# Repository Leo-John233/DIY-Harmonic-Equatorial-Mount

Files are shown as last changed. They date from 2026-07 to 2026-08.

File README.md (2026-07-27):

<div align="center">
  
  
</div>

## 📄 License / 开源协议

本项目采用组合开源协议，对软件和硬件部分分别进行授权：

* **Software / 软件部分** (如固件代码): 采用 [GNU General Public License v3.0 (GPL-3.0)](LICENSE-GPL) 授权，详细信息请参阅 `LICENSE-GPL` 文件
* **Hardware / 硬件部分** (如 PCB 设计、原理图、机械 3D 模型): 采用 [CERN Open Hardware Licence Version 2 - Strongly Reciprocal (CERN-OHL-S v2)](LICENSE-CERN) 授权，详细信息请参阅 `LICENSE-CERN` 文件

若参考了该项目希望能够指明参考来源，注明原作者，保持开源精神，欢迎大家在此基础上进行改进和创新，但请勿将本项目的设计用于商业用途，除非您获得了明确许可

## 🛑致各位试图拿本开源项目“创业”的商业奇才们
本着开源精神，我非常欢迎大家复刻、交流和自己动手做着玩，但如果您是抱着“低价造个赤道仪拿去卖”的伟大商业宏图，并且打算把原作者当免费技术顾问的，请仔细阅读以下几点：

**🚫本项目不提供“保姆级开厂培训”**
开源提供的是设计本身，不是您商业化流水线上的免费技术支持，如果您连最基本的“水平轴承在哪”、“圆弧槽是干啥用的”都看不明白，连 STP 文件导入 SolidWorks 都不知道怎么处理，建议先去补习一下基础的机械常识，我不负责为您解答“怎么装”、“怎么动”、“怎么改”，更不负责给您的工厂流水线工人做技术培训，请不要把原作者当成您的“免费技术顾问”，如果您不懂机械设计，请先学会自己看图纸，学会自己分析问题，学会自己解决问题

**✂️魔改出了 Bug，请自己背锅**
把模型等比缩放、乱改减速机孔位，改完之后跑来跟我抱怨“俯仰调节机构装不上”、“没法适配”、“太难理解”？拜托，自己魔改导致的问题，请不要跑来怪原作者，我都开源了，您还指望我给您的“定制缩水版”做免费 Debug 吗？

**💰嫌贵别用，用了别嫌**
一边刷着小红书觉得这套开源设计“好高级”，一边又跑来跟我吐槽用这套方案“成本涨了200块”、“太麻烦了”，觉得贵、觉得麻烦，您可以不用，既然决定要抄这套作业去赚钱，就别在原作者面前哭穷了，毕竟我也不想看到您辛辛苦苦开了个工厂，结果因为技术问题被客户投诉了还跑来找我背锅

**⚖️友情警告**
想拿这套类似结构随便改个外观就去大规模量产售卖？自己做着玩大家其乐融融，但如果要量产商用，请自己评估好侵权风险，别怪我没提醒过您，出了事请自己承担，别拉上我，开源不等于“免费商用”，如果您想拿去商用，请自己搞定技术壁垒，做好侵权风险评估，做好售后服务准备，做好质量控制准备，做好客户投诉处理准备，做好工厂管理准备，做好资金链管理准备，做好一切商业化运营的准备，不要到时候出了问题还跑来怪原作者

大家都很忙，祝您的“平价赤道仪”大卖，Peace & Love

👉 **[奇文共赏：点击此处阅读“白嫖式创业奇才”的逆天聊天实录](https://github.com/Leo-John233/DIY-Harmonic-Equatorial-Mount/blob/main/images/Chat%20history/readme.md)**

---
## DIY谐波赤道仪（已完成实拍与导星测试）

由于我厌倦了 EQ3D 赤道仪的沉重，我计划用更轻便的谐波赤道仪来替换它。然而市面上的谐波赤道仪价格较高，尤其是与 DIY 可实现的规格相比，因此这个项目就此诞生。该谐波赤道仪旨在不牺牲性能的前提下，兼顾高精度、便携性和经济性

该项目旨在解决业余天文设备中的关键问题：
- 成品支架价格高昂
- 缺乏开放性和灵活性
- 复杂性或与个人设置的不兼容

此款DIY谐波赤道仪优势是：
- 🧰**经济实惠**——总造价低于3000元，加工零件价格低于1500元
- 🪶**相对便携**——不含底座重量7.5公斤
- 🏗️**易于搭建**——专为拥有基本工具的创客设计
- 💪**高性能**——已完成PHD2导星拍摄测试
- ⚠️**关于当前项目状态的说明**⚠️
该项目已完成通电、基础 GoTo、导星和约13kg实际成像负载下的实拍验证，稳定导星时段的 PHD2 总 RMS 通常约为 0.4″ 至 0.6″，不同装配、负载和环境下的结果可能有所差异

## ✨主要特点
| **特征** | **描述** |
| :----- | :----- |
| 安装类型 | GEM德式赤道仪 |
| 传动类型 | 谐波减速器+皮带传动+42步进电机 |
| 有效载重 | 设计最大载重 30 kg（建议配重），无配重设计载重 20-25 kg，当前已完成约 13 kg 实拍验证 |
| 减速器类型 | leaderdrive LHS-25-100-C-III |
| 控制系统 | OnStep/OnStepx |
| 连接类型 | USB-B；WIFI；蓝牙；集成DS3231SN时钟芯片 |
| 硬件功能 | RA轴制动器；RA/DEC轴光电传感器限位；DEC/RA轴光电传感器原点；<br>同时兼容step/dir，spi两种驱动模式(即兼容tmc2209，tmc5160)；12/24v输入 |
| 预计成本 | 2500-2900 RMB |
| 预计重量 | 9.5 kg（包含鸠尾槽和纬度座） |
| 已测导星表现 | 稳定时段 PHD2 总 RMS 通常约为 0.4″ 至 0.6″ |

---

## 最终成效

自制谐波赤道仪的核心部件为 Leaderdrive 拆机二手工业谐波减速器，也适用于同规格的 25-100 谐波减速器
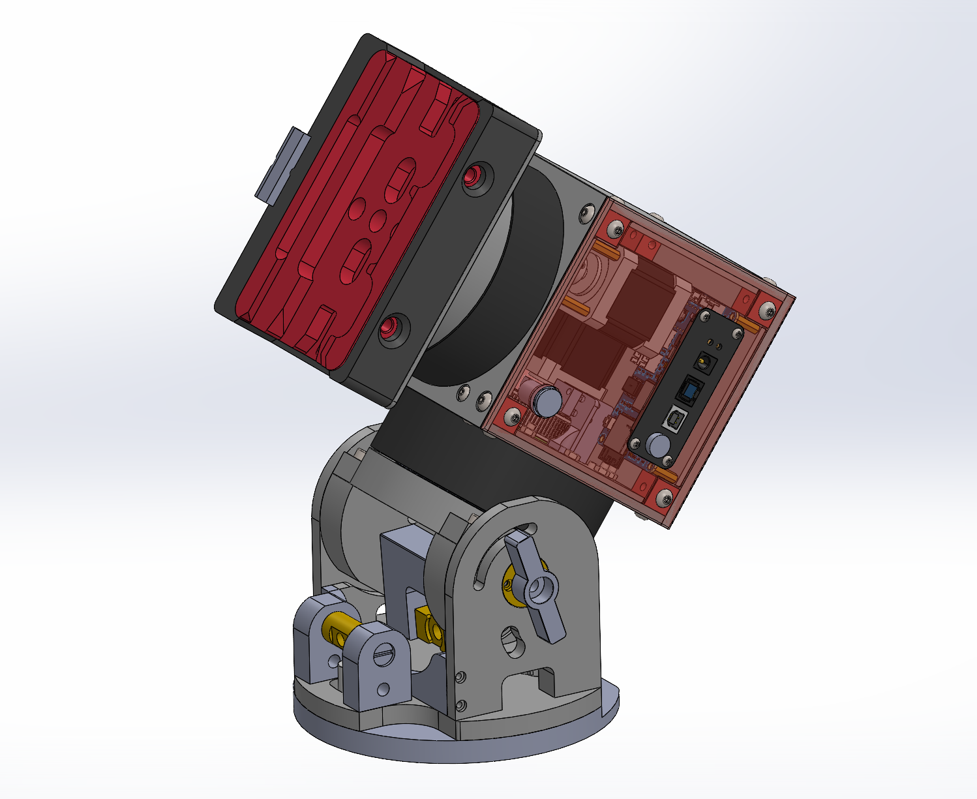
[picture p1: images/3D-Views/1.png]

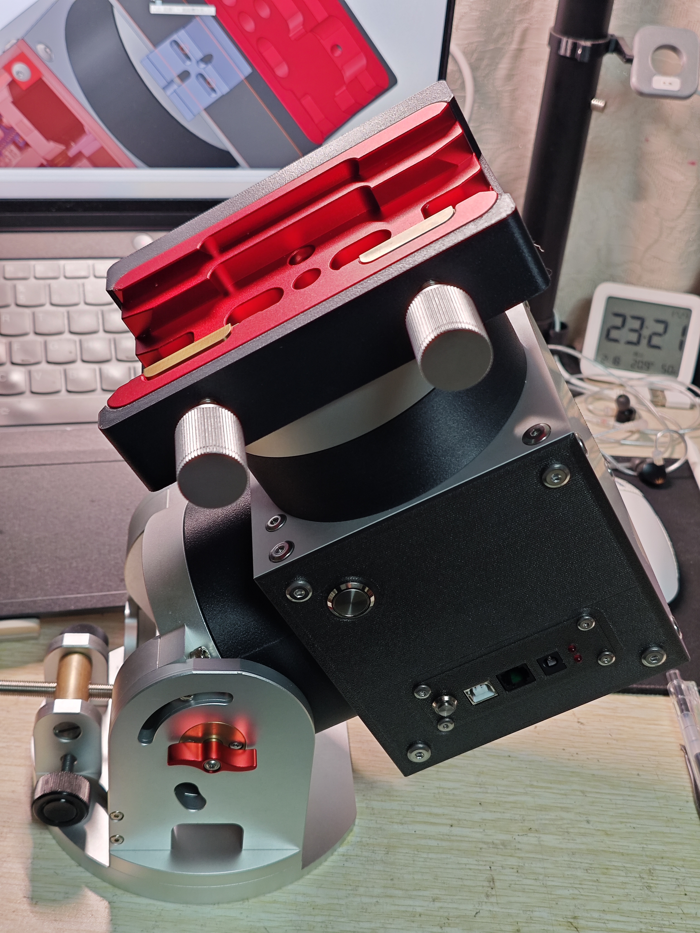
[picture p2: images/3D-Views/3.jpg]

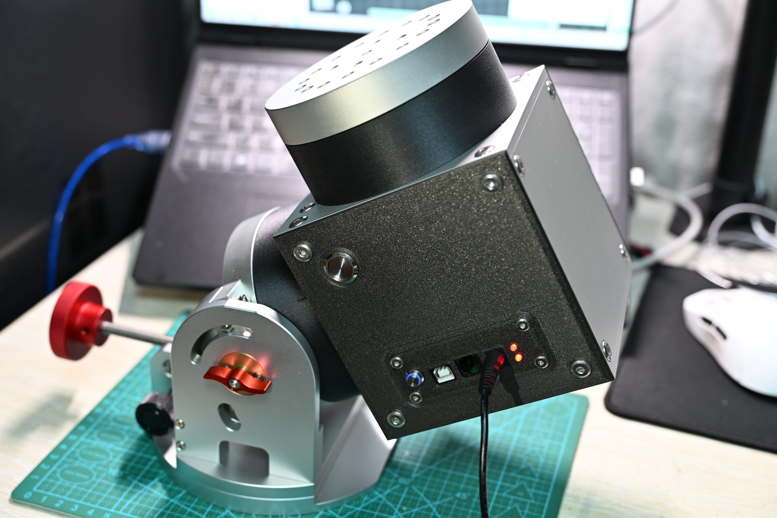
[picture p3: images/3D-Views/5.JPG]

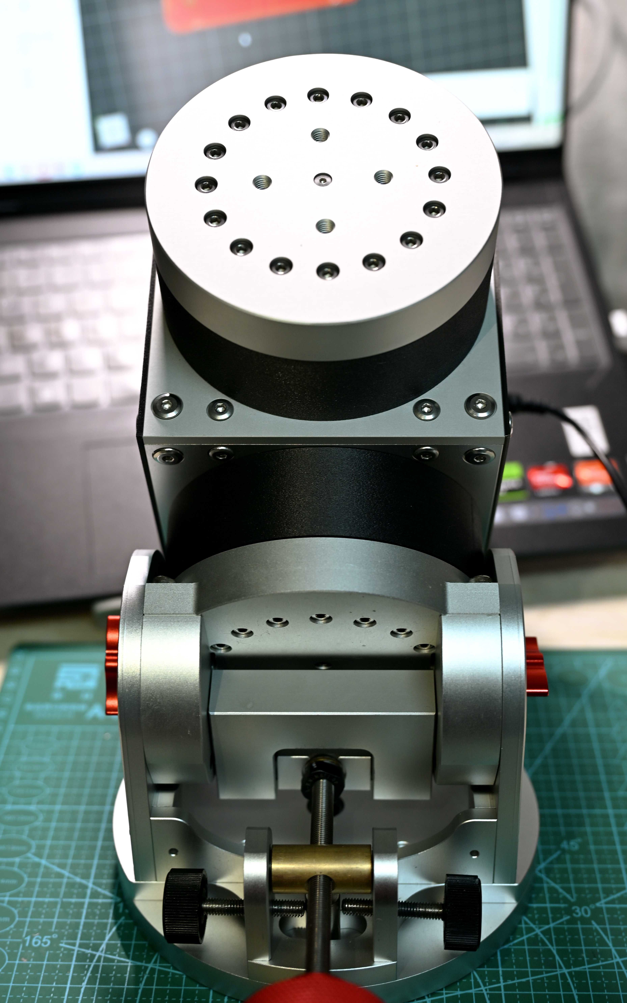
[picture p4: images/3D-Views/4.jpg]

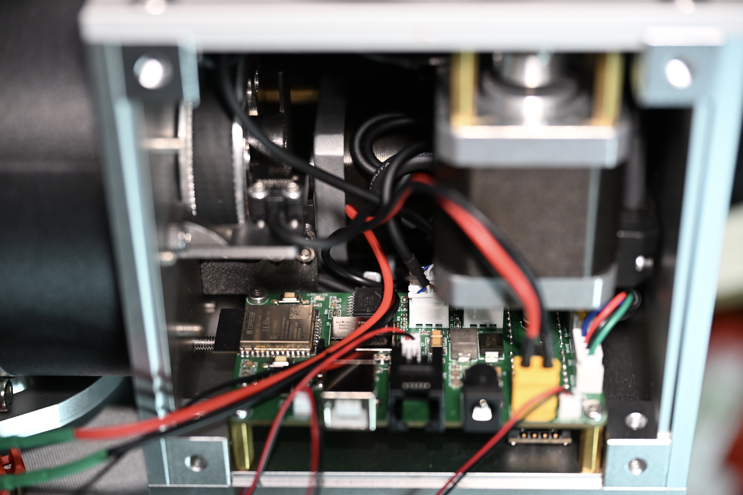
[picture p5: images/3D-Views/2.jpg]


---

## 实拍与导星测试

本次拍摄目标为 **Herschel 36**

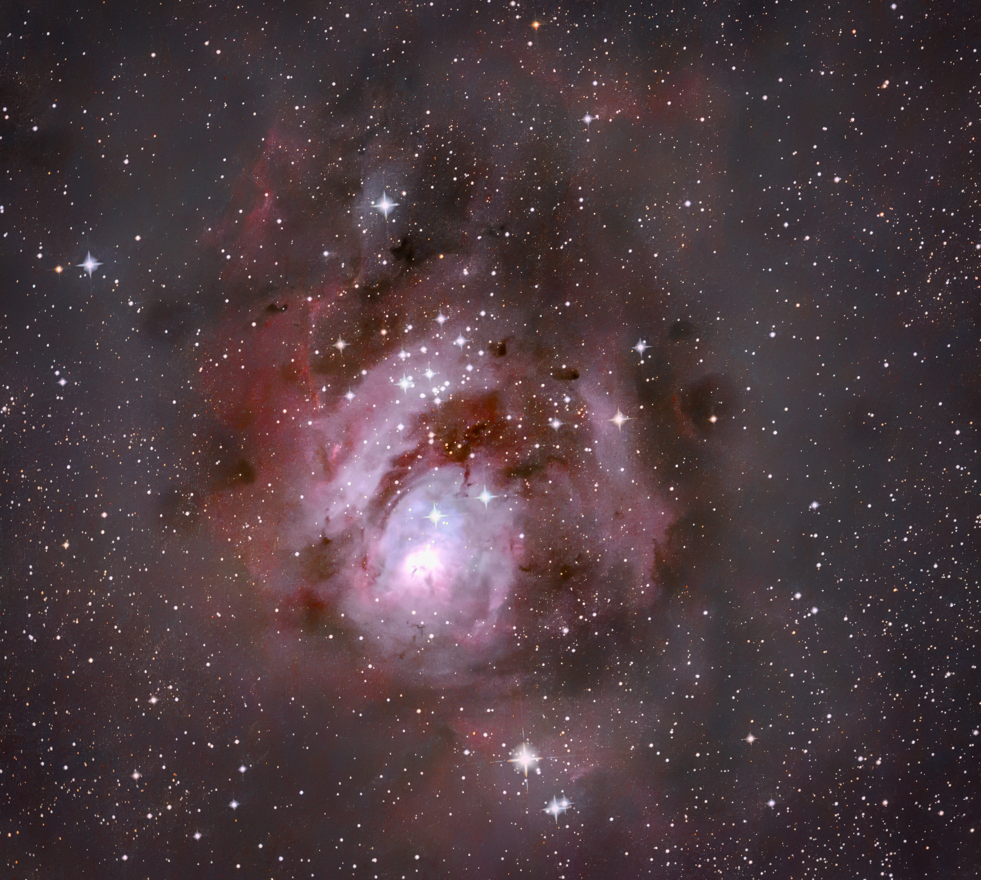
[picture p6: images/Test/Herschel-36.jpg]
Herschel 36


| **实拍项目** | **配置** |
| :----- | :----- |
| 主摄影器材 | 铁皮桶全改小黑，搭配 MPCC 彗差校正镜 |
| 主相机 | Nikon D7000 |
| 导星相机 | ZWO ASI662MC |
| 实际成像负载 | 约 13 kg |
| 测试环境 | 微风 |

## 当前验证状态

- [√] 主控板通电和基础通信
- [√] OnStep ASCOM 连接
- [√] 基础 GoTo 和恒星时跟踪
- [√] PHD2 校准和闭环导星
- [√] Dither 和 Settling
- [√] 约 52 分 45 秒连续导星记录
- [√] 约 13 kg 实际成像负载下的 Herschel 36 实拍
- [√] 不同载重和重心位置下的多夜重复测试
- [√] 无配重与带配重状态下的系统对比
- [ ] 关闭导星修正和 Dither 后的长时间本征周期误差测试
- [ ] 不同焦距、曝光时间和环境条件下的长期实拍验证

## PHD2 导星测试

### 测试配置

| 项目 | 配置 |
| :--- | :--- |
| 测试软件 | PHD2 Guiding 2.6.13 |
| 赤道仪连接 | OnStep ASCOM |
| 导星相机 | ZWO ASI662MC |
| 导星焦距 | 200 mm |
| 导星相机像元尺寸 | 2.9 μm |
| 导星图像比例 | 约 2.99″/px |
| 导星曝光 | 0.2 s |
| 实际成像负载 | 约 13 kg |
| 测试环境 | 微风 |
| 完整记录时长 | 52 分 45 秒 |

### 结果汇总

| 测试片段 | RA RMS | Dec RMS | 总 RMS | 说明 |
| :--- | ---: | ---: | ---: | :--- |
| 稳定导星片段 | 0.43″ | 0.50″ | 0.66″ | PHD2 实时统计截图 |
| 52 分 45 秒完整记录 | 0.45″ | 0.82″ | 0.94″ | 包含 Dither、Settling 和少量异常峰值 |

实际使用过程中，稳定导星阶段的总 RMS 通常约为 0.4″ 至 0.6″。稳定片段截图显示总 RMS 为 0.66″，完整记录由于包含 Dither、Settling 和少量异常峰值，总 RMS 为 0.94″

### 结果分析

- **稳定阶段两轴误差较为均衡**：RA RMS 为 0.43″，Dec RMS 为 0.50″，两轴差值较小，未表现出明显的单轴持续振荡。总 RMS 为 0.66″，按 2.99″/px 的导星图像比例换算约为 0.22 px，其中 RA 约为 0.14 px，Dec 约为 0.17 px
- **完整记录的 RMS 主要由 Dec 瞬态波动拉高**：完整记录中的 RA RMS 为 0.45″，与稳定片段接近，说明 RA 长时间表现基本保持一致。Dec RMS 上升至 0.82″，表明完整记录中的 Dither、Settling、微风或少量异常峰值主要影响了 Dec 统计结果，不代表稳定跟踪阶段持续存在 0.82″ 的 Dec 误差
- **约 13 kg 实际负载下维持稳定导星**：在铁皮桶全改小黑、Nikon D7000、MPCC 和导星系统组成的约 13 kg 成像负载下，稳定阶段未观察到明显发散或持续性机械振荡，说明当前结构刚性、传动控制和导星响应能够满足实际成像需求
- **0.2 s 导星曝光体现了较快的修正响应**：较短曝光有助于快速修正误差，但也更容易受到视宁度和瞬时扰动影响。因此，0.4″ 至 0.6″ 应视为本次设备、参数和环境组合下的实测表现，不应直接作为所有场景下的固定性能指标
- **频域结果不能直接作为本征周期误差**：频域分析中选中的低频分量周期约为 2206.6 s，显示振幅约为 0.1″。由于数据来自导星记录，并包含低频漂移、Dither 和 Settling，该结果只能用于观察频率成分，不能直接认定为谐波减速器的本征周期误差

<details>
<summary>展开查看 PHD2 测试截图与频域分析</summary>

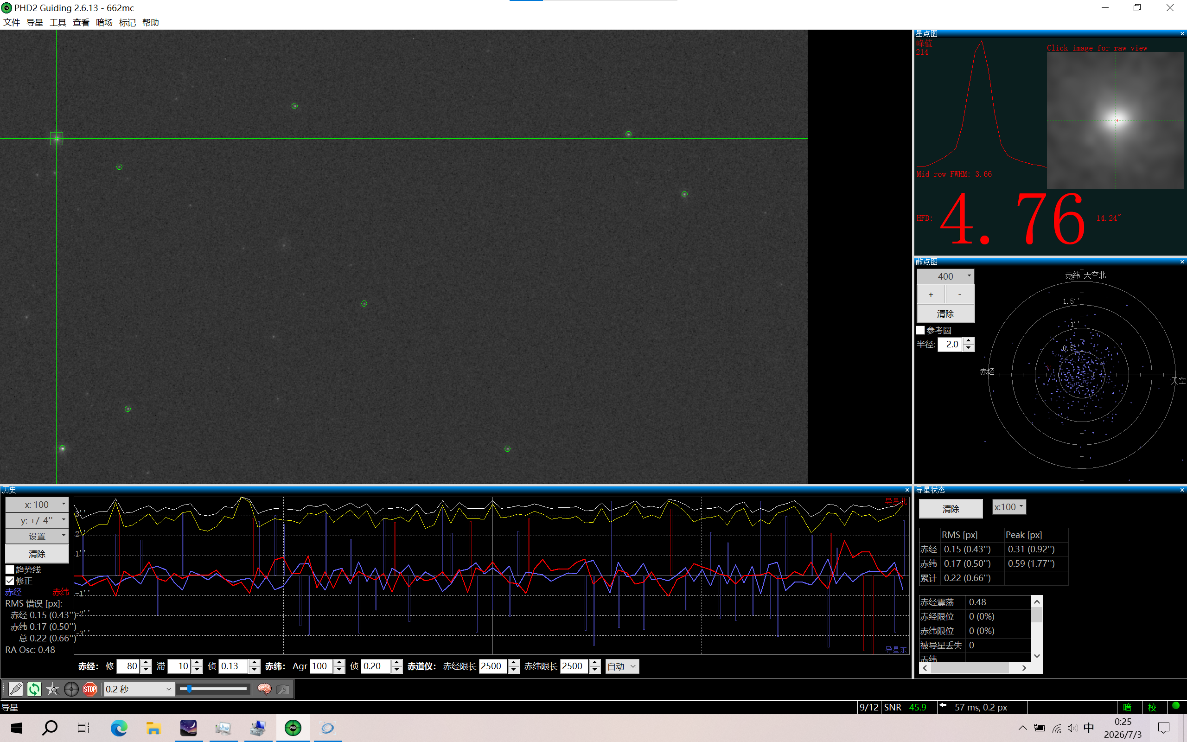
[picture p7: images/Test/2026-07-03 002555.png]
PHD2 stable guiding


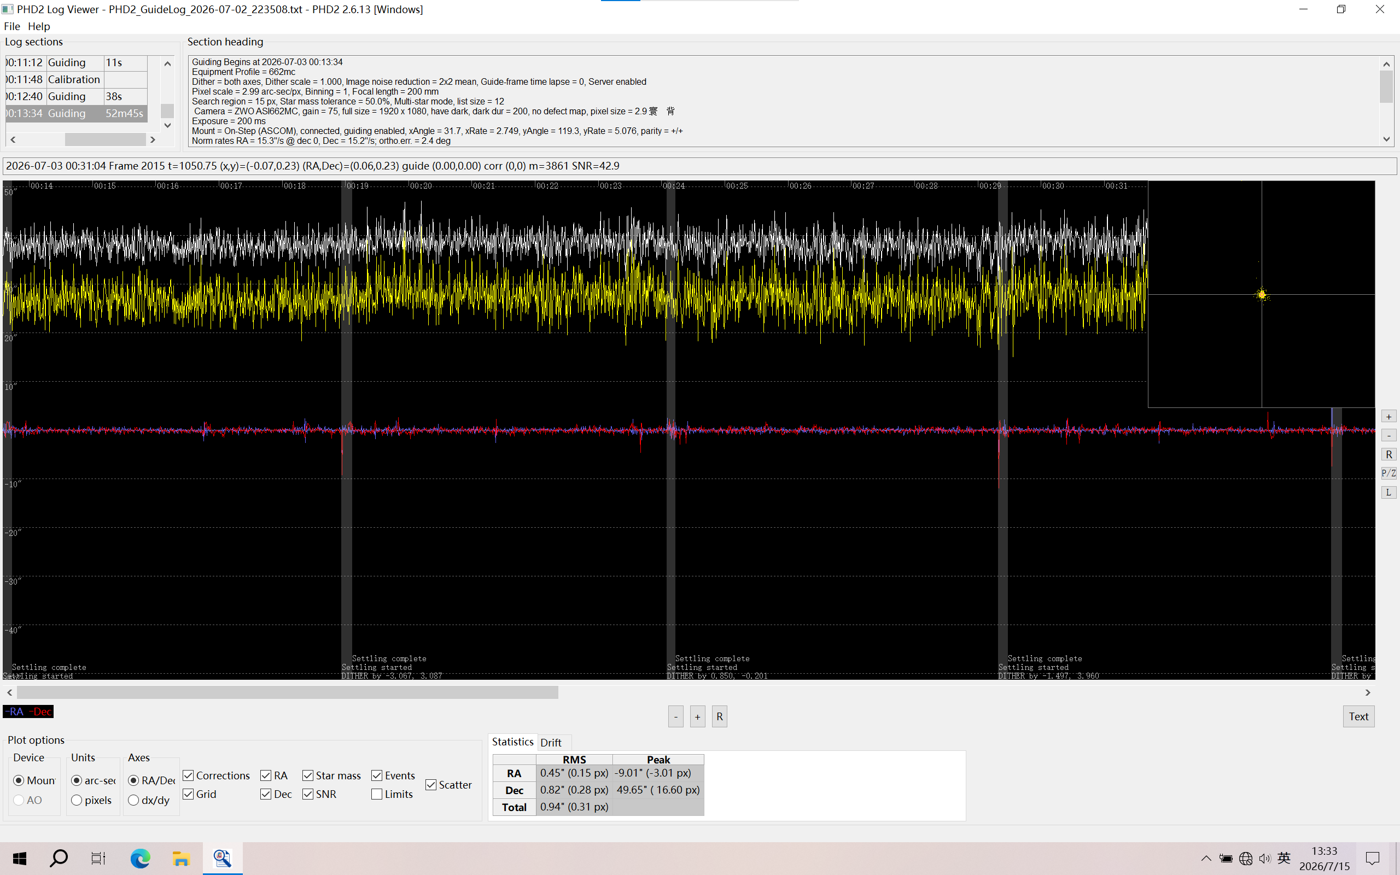
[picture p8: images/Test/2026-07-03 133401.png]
PHD2 complete log


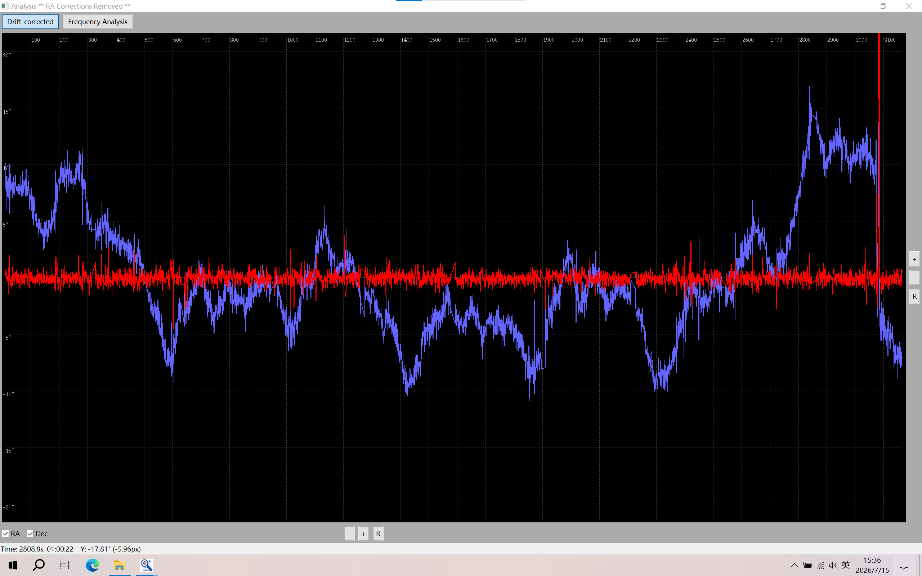
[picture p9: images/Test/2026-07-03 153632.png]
PHD2 drift-corrected analysis


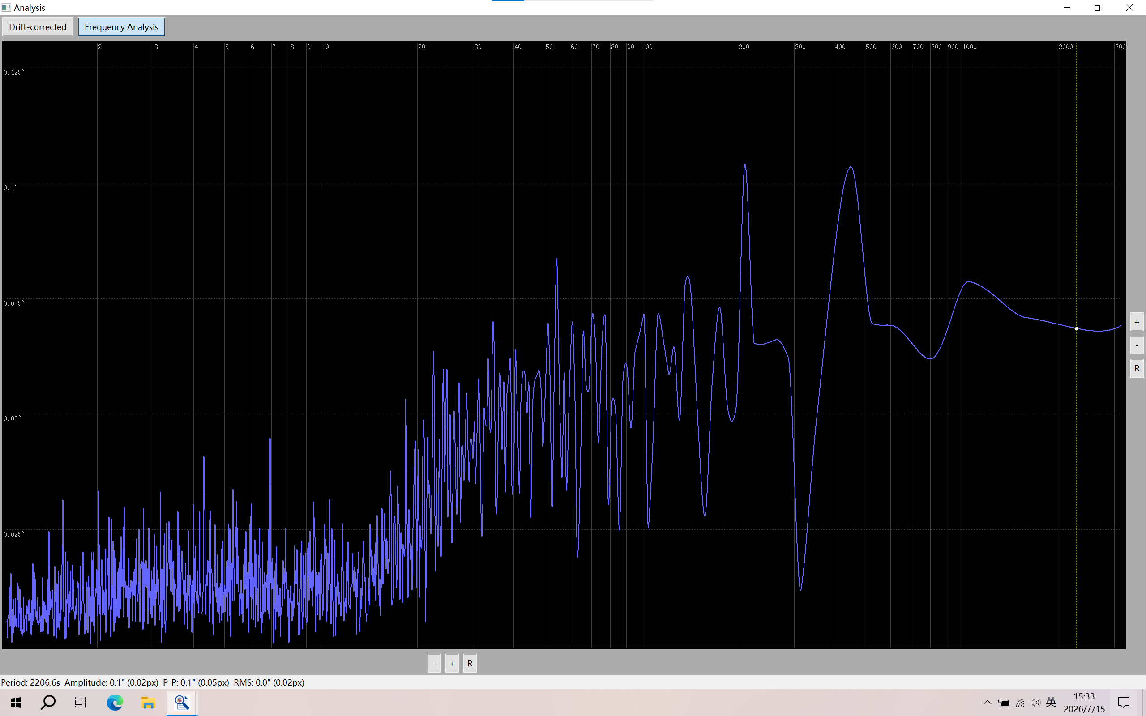
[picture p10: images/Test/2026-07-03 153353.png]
PHD2 frequency analysis


移除 RA 导星修正后的曲线仍包含低频漂移、Dither 和 Settling 的影响，不能直接将整段曲线的峰峰值视为谐波减速器的本征周期误差

频域分析中选中的低频分量周期约为 2206.6 s，软件显示振幅约为 0.1″。该结果仅用于观察频率成分，不能替代关闭导星修正和 Dither 后进行的长时间无导星周期误差测试

</details>

---

## 🔗 物料清单 (BOM)

请参阅 [BOM.md](https://github.com/Leo-John233/DIY-Harmonic-Equatorial-Mount/tree/main/BOM)

**预计总成本：约2500RMB（含纬度座）**

本项目的主体结构高度依赖定制，主要部件包含两台 25-100 规格的谐波减速器，提供了极高的传动比与扭矩，底座接口可根据个人习惯适配主流的三脚架

*注：价格为近似值，可能因电机供应商、CNC 加工批次和地点而异*

---

## 🔌电子部分概览

控制系统完全采用定制设计，并围绕紧凑结构构建，它包括：

* **基于 ESP32-WROOM-32E16N 的主控核心**，运行强大的 [OnStep/OnStepX](https://onstep.groups.io/g/main/wiki) 系统
* **搭配 ESP07S 无线连接**，提供高效的无线/有线通讯
* **TMC系列步进电机驱动器**，实现赤经与赤纬轴精确、静音的微步进控制与指向
* **高效电源管理方案**，板载 TPS5450 降压模块和 AMS1117 LDO 稳压芯片，确保高负载下系统电压的纯净与稳定
* 集成 **零位传感器和限位开关** 接口，在运行中保障设备的安全
* 支持通过 Wi-Fi、蓝牙或 USB 路由进行远程控制，无缝对接主流天文摄影软件生态 (N.I.N.A., INDI, ASCOM 等)
* 控制板在 PCB 走线设计上充分考虑了扩展性需求，通过主板驱动器插槽旁的排针跳线 (Jumpers)，您可以轻松地在先进的 **SPI 智能控制模式**和传统的 **STEP/DIR 独立模式**之间进行物理切换(切换后需刷写固件)

* **TMC5160 SPI 模式 (推荐配置) 🚀**
    * **硬件设置**：使用跳线帽闭合 SPI 专用的针脚组，将 ESP32 的 SPI 总线直接连接至 TMC5160 驱动器
    * **系统优势**：彻底告别手动调节电位器，允许 OnStep 固件直接读取和写入寄存器，您可以在 Web 界面或 `Config.h` 中实时配置运行/保持电流、精确设置细分数（Microstepping），并在 StealthChop（极致静音）和 SpreadCycle（高动态扭矩）模式之间智能切换，最大化释放谐波减速器的性能
    * **固件配合**：在 `Config.h` 中将赤经/赤纬驱动模型定义为 `TMC5160_SPI`

* **传统 STEP/DIR 模式 (向下兼容) 🔌**
    * **硬件设置**：断开 SPI 通讯跳线
    * **适用场景**：作为一种可靠的底层回退方案。如果您需要临时替换为普通的 A4988、DRV8825，或者仅使用 TMC 驱动器的 Standalone (独立运行) 模式，此设计提供了极大的硬件容错率和维修便利性
    * **固件配合**：需要在 `Config.h` 中精确填写您通过跳线帽设定的细分值，并**必须手动使用万用表和陶瓷螺丝刀**调节驱动器上的 VREF 电位器来设定电机电流

所有电路板原理图及 PCB Layout（严格把控了安全间距、过孔尺寸和大电流线宽）均使用开源工具设计，您可以在 [JLC PCB](https://member.jlc.com/?spm=PCB.Homepage) 订购 PCB或对其进行重新组合以满足您的需求

### PCB 制作与装配说明

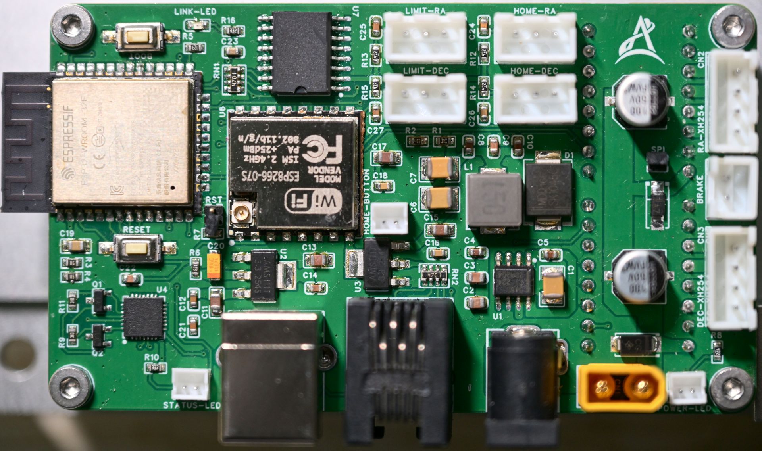
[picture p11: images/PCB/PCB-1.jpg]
PCB front


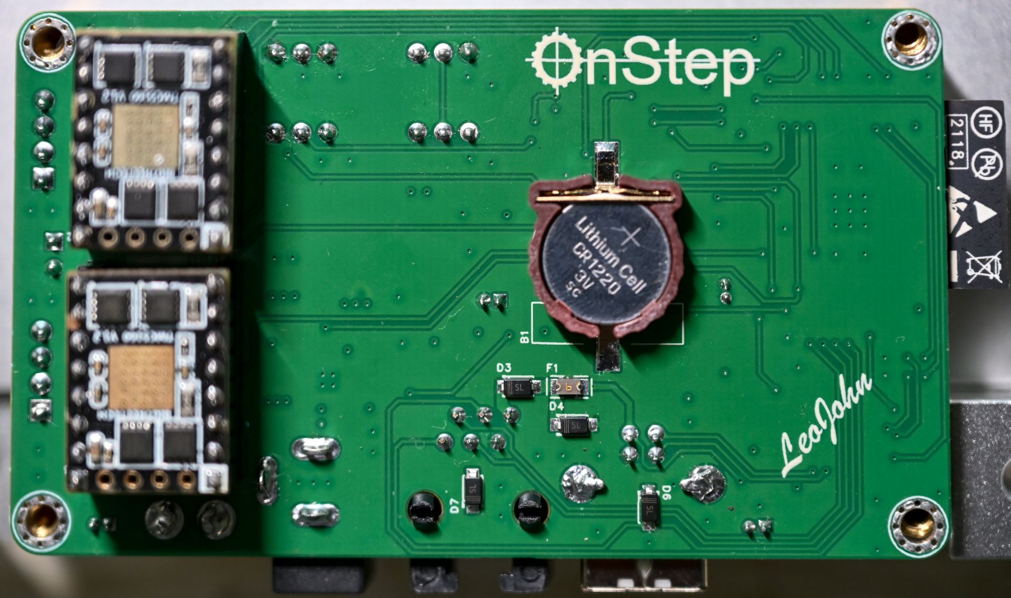
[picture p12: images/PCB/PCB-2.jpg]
PCB reverse-side TMC5160 installation


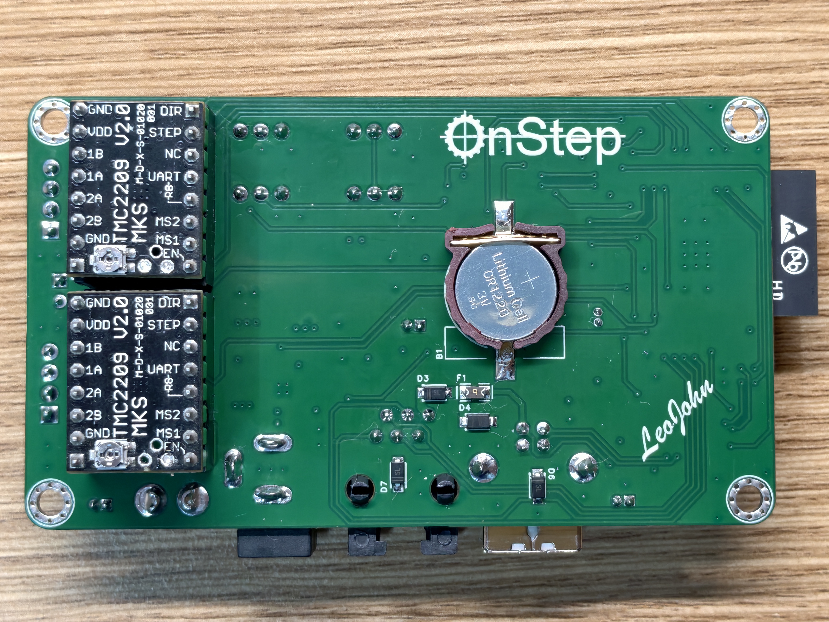
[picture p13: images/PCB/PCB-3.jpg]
PCB reverse-side TMC2209 installation


PCB 制作和装配建议按以下顺序进行：

1. **提交 PCB 文件**
   * 将仓库中对应版本的 Gerber 压缩包直接上传至 PCB 厂商
   * 下单前检查板框尺寸、安装孔、槽位和连接器开口，避免生产平台自动缩放或修改外形
   * 如果自行修改板厚、铜厚、表面处理或元件封装，需要重新确认外壳间隙、连接器高度和大电流走线能力

2. **核对元件和方向**
   * 焊接前根据原理图、BOM、PCB 丝印和封装方向逐项核对元件
   * 重点检查二极管、LED、电解电容、稳压芯片、ESP32、ESP-07S 和其他有方向要求的器件
   * CR1220 电池按 PCB 丝印方向安装，照片所示安装方式为正极朝外
   * ESP32 天线区域附近不要布置金属挡板、屏蔽片或紧贴外壳，以免影响无线连接

3. **建议焊接顺序**
   * 先焊接电阻、电容、二极管和小型 IC 等低矮贴片器件
   * 再焊接电源模块、排针、驱动器插座、按键和 LED 接口
   * 最后安装 XH2.54 插座、USB、网络接口、DC 插座、XT60 和其他较高连接器
   * TMC 驱动器、ESP 模块和纽扣电池应在完成短路检查和基础供电测试后再安装

4. **驱动器安装**
   * 驱动器安装在 PCB 背面，插入前必须核对 PCB 丝印与驱动器上的 `GND`、`VM`、`EN`、`STEP` 和 `DIR` 引脚
   * 不同厂商的 TMC2209 或 TMC5160 模块可能存在引脚、焊盘或散热结构差异，不能只根据模块外观判断方向
   * 使用 TMC5160 SPI 模式时闭合对应 SPI 跳线，并在固件中选择 `TMC5160_SPI`
   * 使用 TMC2209 或其他 STEP/DIR 驱动器时断开 SPI 跳线，并按照实际硬件设置填写细分参数和驱动电流
   * 驱动器插反或带电插拔可能立即损坏驱动器和主控板

5. **首次通电检查**
   * 通电前使用万用表检查主电源正负极之间是否存在明显短路
   * 首次测试建议使用带限流功能的实验电源，并从较低限流值开始
   * 首次通电时不要连接电机、传感器和驱动器，先确认电源部分没有异常发热，并检查主要电压轨是否正常
   * 确认主控、USB 通信和无线连接正常后，再逐个安装驱动器并连接 RA、Dec 电机
   * 初次电机测试应使用较低电流和较低速度，确认转向、原点和限位逻辑正确后再提高参数

6. **接口连接**
   * `LIMIT-RA`、`LIMIT-DEC`、`HOME-RA` 和 `HOME-DEC` 分别连接对应轴的限位和原点传感器
   * `RA-XH2.54`、`DEC-XH2.54` 和 `BRAKE` 接口应根据原理图确认引脚顺序后连接
   * 状态灯、连接灯和电源灯接口需要注意 LED 极性
   * 不建议同时连接多个主电源入口，除非已根据原理图确认其连接关系和使用方式

> 💡**警告：任何焊接、驱动器插拔、跳线调整、传感器接线或电机接线操作都必须在主电源和 USB 供电完全断开后进行，首次上电前应再次检查电源极性、焊锡短路、驱动器方向和连接器引脚顺序**

## 💻固件配置与刷写

谐波赤道仪的主控搭载了 **ESP32-WROOM-32E (16MB)**，这款大容量核心不仅能轻松运行复杂的 [OnStep / OnStepX](https://onstep.groups.io/g/main/wiki) 固件，还为内置星表、高精度对位模型 (Pointing Model) 以及功能丰富的 Smart Web UI 留出了充足的存储空间

请参阅 [Firmware_Setup.md](https://github.com/Leo-John233/DIY-Harmonic-Equatorial-Mount/blob/main/software/Firmware_Setup.md) 获取完整的 `Config.h` 参数表及详细引脚映射

---

## 🛠️机械部分组装指南

请参阅 [Assembly.md](https://github.com/Leo-John233/DIY-Harmonic-Equatorial-Mount/blob/main/hardware/Assembly.md)

每个组件都经过精心挑选或设计，以确保高机械精度和易于组装，从 CNC 加工的坚固铝制主体、25-100 谐波减速器，到步进电机和控制器的 3D 打印防护外壳，每一步都经过了严格的测试与指向模型校准，以实现亚角秒级的跟踪精度

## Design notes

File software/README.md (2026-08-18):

---

## 📝 摘要 (Summary)

本项目以 [原始 OnStep 4.24](https://github.com/hjd1964/OnStep/tree/release-4.24) 为对照基准，说明本地固件针对 MaxESP3 谐波赤道仪做出的实际修改

修改围绕三条主线展开，开机后先建立保持力矩并确认位置，运动中保留安全中断与反向脱困能力，驱动细分切换时保持双轴同步

具体改进包括开机电机保持、位置可信状态、GOTO 与 Tracking 安全锁、物理限位反向脱困、三阶段自动回零、GOTO 中断分类、客户端状态修复以及 MaxESP3 TMC2209 共享细分切换

本文只展示本地代码相对原始 OnStep 4.24 新增或改进的实现，不重复粘贴未修改的上游代码

---

## 📌 背景与痛点 (Pain Points)

原始 OnStep 4.24 是面向多种赤道仪和经纬仪的通用固件。将它用于当前 MaxESP3 谐波赤道仪时，还需要处理下面这些实际问题

1. **开机可能溜车**

   谐波赤道仪通常没有传统离合结构。镜筒失衡时，如果驱动器在上电初期没有保持力矩，机械结构可能在重力作用下滑落

2. **上电位置不能直接信任**

   开环步进系统断电后无法证明机械位置没有变化。Home 传感器启用时，开机后的坐标只能在真实回零完成后重新建立

3. **未回零时自动动作风险较高**

   N.I.N.A、ASCOM 或其他 LX200 客户端可能在连接后发送 GOTO、Sync、Park 或 Tracking 指令。如果当前位置不可信，自动动作可能造成错误指向、绕线或机械碰撞

4. **安全中断后不能恢复成正常到达**

   GOTO 因限位、驱动故障或回零失败而停止时，不能继续走正常完成流程，更不能在错误坐标上自动开始 Tracking

5. **触发物理限位后仍需要反向脱困**

   如果限位触发后锁死所有手动方向，设备会停在开关上无法退出。如果完全不限制方向，又可能继续向危险侧运动

6. **Home 开关位置不一定是真实机械零位**

   传感器安装位置与目标零位可能存在角度偏差，需要在快速搜索和慢速精找后继续执行可配置的双轴偏置

7. **回零失败不能伪装成成功**

   传感器未触发、阶段超时或电机启动失败时，系统必须保留位置恢复要求，不能只因为回零状态机结束就开放 GOTO

8. **MaxESP3 的共享模式引脚需要双轴同步处理**

   MaxESP3 的 Axis1 与 Axis2 共用 M0 和 M1。独立模式 TMC2209 如果按原始双轴独立逻辑切换细分，可能出现硬件细分已经改变而软件步距没有同步的问题

9. **首次连接可能误报 Home**

   `atHome` 只能说明内部状态位于 Home，不能单独证明当前机械位置可信。客户端状态必须同时检查位置恢复状态

10. **有无 Home 传感器都需要可恢复路径**

    有传感器时可以自动 Find Home，没有传感器时则需要保留坐标 Home 和人工 Set Home 的恢复方式，不能被新增安全锁永久限制

---

## ✨ 核心功能特性 (Key Features)

1. **开机电机保持**

   上电后使能双轴驱动器，使用跟踪细分和跟踪电流保持当前位置，但不启动 Tracking，也不声明已经完成 Home

2. **独立的位置可信状态**

   使用 `mountPositionTrusted` 与 `positionRecoveryRequired` 区分正常使用、仅允许坐标回零和位置完全不可信三种状态

3. **自动命令统一进入安全检查**

   GOTO、Sync、Park 和开启 Tracking 都依赖 `positionReady()`，不会因为命令入口不同而绕过回零要求

4. **未回零仍允许手动移动**

   手动 East、West、North、South 不依赖位置可信状态，方便用户找零、调整姿态和处理机械风险

5. **物理限位反向脱困**

   限位触发后记录危险方向，只拒绝继续撞击的一侧，允许相反方向手动退出

6. **三阶段自动回零**

   自动 Home 依次执行快速搜索、慢速精找和零位偏置，双轴全部停稳后才重建坐标

7. **ST4 长按一键回零**

   同时长按 East 和 West 超过 3 秒可启动快速回零，并通过按键锁避免残留输入干扰状态机

8. **GOTO 中断分类**

   区分普通停止、物理硬停止和位置丢失，按风险等级决定是否停止 Tracking 和要求重新 Home

9. **客户端状态修复**

   `:GU#` 只有在 `atHome` 与 `positionReady()` 同时成立时才返回 `H`。被拒绝的 `:Te#` 会立即回复失败，不再让客户端等待通信超时

10. **MaxESP3 TMC2209 共享细分支持**

    双轴共享 M0 和 M1 时统一判断 GOTO 模式，在可安全切换的位置同步更新硬件模式与软件步距

11. **配置校验与中文说明**

    新增开机策略、回零速度、偏置角度和共享细分规则校验，并在 `Config.h` 与 MaxESP3 引脚文件中补充中文说明

---

## 🛠️ 代码修改与源码对照 (Code Modification Guide)

下表汇总本地代码相对原始 OnStep 4.24 的 20 项修改。后文按相同编号给出修改代码和功能说明

| 编号 | 修改主题 | 主要文件 | 相对原始 OnStep 4.24 的变化 | 修改带来的功能 |
| --- | --- | --- | --- | --- |
| 1 | 开机保持与位置确认 | `Config.h` `OnStep.ino` | 新增开机回零要求和电机保持策略 | 上电后保持双轴但不启动 Tracking |
| 2 | 位置可信模型 | `OnStep.ino` | 新增位置可信状态 恢复状态和 GOTO 中断类型 | 区分正常使用 坐标回零恢复和位置丢失 |
| 3 | ST4 一键回零 | `Guide.ino` | 新增长按 East 与 West 启动回零的按键逻辑 | 无需上位机即可触发自动回零 |
| 4 | GOTO 与 Sync 安全锁 | `Goto.ino` | 将 `positionReady()` 纳入 GOTO 和 Sync 校验 | 位置恢复前禁止自动指向和同步 |
| 5 | Tracking 失败反馈 | `Command.ino` | 开启 Tracking 前检查位置并立即返回结果 | 避免错误启动和客户端通信超时 |
| 6 | Park 安全锁 | `Park.ino` | Park 前增加位置可信检查 | 防止使用错误坐标执行驻留 |
| 7 | Guide 反向脱困 | `Guide.ino` | 按限位方向拦截 Guide 并保留反向移动 | 阻止继续撞限位同时允许退出危险位置 |
| 8 | 物理限位方向记录 | `OnStep.ino` | 记录双轴危险方向并判断是否已经逃离限位 | 实现硬停止和反向移动后的自动解锁 |
| 9 | Home 状态修复 | `Command.ino` | `:GU#` 同时检查 `atHome` 和 `positionReady()` | 避免客户端首次连接误报已经回零 |
| 10 | 三阶段自动回零 | `Home.ino` | 新增慢速精找和零位偏置阶段 | 从找到传感器提升为恢复真实机械零位 |
| 11 | Home 参数配置 | `Config.h` `Home.ino` | 回零速度 超时和双轴偏置改为可配置 | 便于适配不同传动比和传感器位置 |
| 12 | 回零失败保护 | `Home.ino` | 阶段超时或电机启动失败时保留位置锁 | 防止失败流程被当作回零成功 |
| 13 | 回零成功判定 | `Home.ino` | 只在 `FH_DONE` 中重新建立可信位置 | 确保全部阶段完成后才开放自动动作 |
| 14 | 无传感器恢复路径 | `Home.ino` | `HOME_SENSE` 关闭时保留坐标 Home | 无传感器配置仍可完成位置恢复 |
| 15 | 人工 Set Home 恢复 | `Home.ino` | Set Home 后统一清除中断并恢复可信位置 | 提供明确的人工位置恢复入口 |
| 16 | 坐标 Home 中断保护 | `MoveTo.ino` | 检查坐标 Home 是否完整结束 | 中断的回零不会错误解除位置锁 |
| 17 | GOTO 分类收尾 | `Goto.ino` `MoveTo.ino` | 按正常到达 普通停止 硬停止和位置丢失分别处理 | 防止安全中断后自动进入 Tracking |
| 18 | 停止等级标记 | `OnStep.ino` | `stopSlewingAndTracking()` 按停止来源写入中断等级 | 按风险决定是否要求重新回零 |
| 19 | MaxESP3 引脚与校验 | `Pins.MaxESP3.h` `Validate.MaxESP3.h` `Validate.h` `Validate.TMC2209.h` | 重整引脚定义并增加共享模式配置校验 | 让固件配置匹配本地 MaxESP3 硬件 |
| 20 | TMC2209 双轴细分切换 | `Timer.ino` `StepMode.ino` | 共享 M0 和 M1 时同步切换双轴硬件模式与软件步距 | 在 Tracking 与 GOTO 间切换时保持双轴坐标一致 |

### 1. 开机自动使能电机并要求位置确认

- **对照基准**：原始 OnStep 4.24 没有独立的开机回零要求和电机保持选项
- **修改文件**：`Config.h`、`OnStep.ino`
- **修改逻辑**：新增三个彼此独立的策略开关，并在启动流程中分别处理位置状态和驱动器保持

```cpp
// Config.h
#define HOME_REQUIRED_ON_BOOT          ON
#define HOME_REQUIRED_AFTER_LIMIT      ON
#define MOTOR_HOLD_ON_BOOT             ON
```

```cpp
// OnStep.ino
#if HOME_REQUIRED_ON_BOOT == ON
  #if MOUNT_TYPE != ALTAZM
    #if HOME_SENSE == OFF
      requireCoordinateHomeRecovery();
    #else
      invalidatePositionReference();
    #endif

    gotoAbortState = GOTO_ABORT_NONE;
    trackingState = TrackingNone;
    lastTrackingState = TrackingNone;
    abortTrackingState = TrackingNone;
    safetyLimitsOn = false;
  #endif
#endif

#if MOTOR_HOLD_ON_BOOT == ON
  #if MOUNT_TYPE != ALTAZM
    enableStepperDrivers();
    axis1DriverTrackingMode(false);
    axis2DriverTrackingMode(false);
  #endif
#endif
```

**修改带来的功能**

开机后电机立即获得保持力矩。Tracking 保持关闭，有 Home 传感器时位置被标记为不可信，没有 Home 传感器时只保留返回坐标 Home 的能力

---

### 2. 新增位置可信状态与 GOTO 中断分类

- **对照基准**：原始 OnStep 4.24 主要依赖 `atHome`、`trackingState` 和 `generalError`，没有独立的位置可信模型
- **修改文件**：`OnStep.ino`
- **修改逻辑**：新增位置状态、恢复状态和 GOTO 中断类型

```cpp
enum GotoAbortState {
  GOTO_ABORT_NONE,
  GOTO_ABORT_STOPPED,
  GOTO_ABORT_HARD_STOP,
  GOTO_ABORT_POSITION_LOST
};

GotoAbortState gotoAbortState = GOTO_ABORT_NONE;
bool gotoStartTrackingOnSuccess = false;
bool mountPositionTrusted = true;
bool positionRecoveryRequired = false;
```

```cpp
bool positionReady() {
  return mountPositionTrusted && !positionRecoveryRequired;
}

bool positionHomeReturnOnly() {
  return mountPositionTrusted && positionRecoveryRequired;
}

void requireCoordinateHomeRecovery() {
  mountPositionTrusted = true;
  positionRecoveryRequired = true;
  gotoStartTrackingOnSuccess = false;
}

void invalidatePositionReference() {
  mountPositionTrusted = false;
  positionRecoveryRequired = true;
  gotoStartTrackingOnSuccess = false;
}

void completePositionRecovery() {
  mountPositionTrusted = true;
  positionRecoveryRequired = false;
  gotoAbortState = GOTO_ABORT_NONE;
  gotoStartTrackingOnSuccess = false;
  clearPhysicalLimitState();
}
```

**修改带来的功能**

停止运动不再等于位置可信。限位、故障、回零失败和正常停止可以进入不同的恢复路径，所有自动动作共用同一套位置判断

---

### 3. 复用 ST4 接口实现实体按键一键回零

- **对照基准**：原始 OnStep 4.24 的 East 与 West 长按用于 Alt Mode，没有 3 秒 Find Home 入口
- **修改文件**：`Guide.ino`
- **修改逻辑**：增加 3 秒组合键和释放锁，保留原有 2 秒 Alt Mode

```cpp
static bool homingLockout = false;

if (homingLockout) {
  if (!st4e.isDown() && !st4w.isDown() &&
      !st4n.isDown() && !st4s.isDown()) {
    homingLockout = false;
  }
  return;
}

if (trackingState != TrackingMoveTo && !waitingHome) {
  if (st4e.isDown() && st4w.isDown()) {
    if (st4e.timeDown() > 3000 && st4w.timeDown() > 3000) {
      homingLockout = true;
      soundBeep();
      altModeA = false;
      stopGuideAxis1();
      stopGuideAxis2();
      stopSlewingAndTracking(SS_ALL_FAST);
      goHome(true);
      return;
    }
  }
}
```

**修改带来的功能**

不连接电脑也能启动自动回零。触发后会清理 Alt Mode 和当前运动，全部按键松开后才恢复 ST4 输入，避免残留按压干扰回零

---

### 4. 统一拦截未恢复状态下的 GOTO 与 Sync

- **对照基准**：原始 `validateGoto()` 只检查 Park、电机使能、运动状态和驱动故障
- **修改文件**：`Goto.ino`
- **修改逻辑**：在所有 GOTO 与 Sync 共用的校验函数中加入 `positionReady()`

```cpp
CommandErrors validateGoto() {
  if (parkStatus != NotParked)                 return CE_SLEW_ERR_IN_PARK;
  if (!axis1Enabled)                           return CE_SLEW_ERR_IN_STANDBY;
  if (trackingSyncInProgress())                return CE_MOUNT_IN_MOTION;
  if (trackingState == TrackingMoveTo)         return CE_GOTO_ERR_GOTO;
  if (guideDirAxis1 || guideDirAxis2)          return CE_MOUNT_IN_MOTION;
  if (faultAxis1 || faultAxis2)                return CE_SLEW_ERR_HARDWARE_FAULT;
  if (!positionReady())                        return CE_SLEW_ERR_IN_STANDBY;
  return CE_NONE;
}
```

**修改带来的功能**

`:MS#`、Sync 和其他自动指向入口都无法绕过位置检查。位置未恢复时返回 standby，上游原有的地平线、双轴范围、中天和墩侧校验继续保留

---

### 5. Tracking 指令被拦截时立即回复失败

- **对照基准**：原始 `:Te#` 没有位置可信检查
- **修改文件**：`Command.ino`
- **修改逻辑**：只拦截开启 Tracking，不影响停止 Tracking，并保留布尔回复

```cpp
if (command[0] == 'T' && parameter[0] == 0) {
  const bool trackingBlockedUntilRecovery =
    command[1] == 'e' && !positionReady();

  if (trackingBlockedUntilRecovery) {
    commandError = CE_SLEW_ERR_IN_STANDBY;
  } else {
    // 原始 Tracking 命令继续处理
  }
}
```

**修改带来的功能**

位置不可信时 `:Te#` 不会启动恒星跟踪。命令处理器会立即返回 `0`，避免 N.I.N.A 或 ASCOM 一直等待到通信超时

---

### 6. Park 位置增加可信状态检查

- **对照基准**：原始 OnStep 4.24 在设备停止且驱动无故障时即可保存 Park 位置
- **修改文件**：`Park.ino`
- **修改逻辑**：保存 Park 前增加位置可信检查

```cpp
CommandErrors setPark() {
  if (parkStatus == ParkFailed)         return CE_PARK_FAILED;
  if (parkStatus == Parked)             return CE_PARKED;
  if (isSlewing())                      return CE_MOUNT_IN_MOTION;
  if (faultAxis1 || faultAxis2)         return CE_SLEW_ERR_HARDWARE_FAULT;
  if (!positionReady())                 return CE_SLEW_ERR_IN_STANDBY;

  // 原始 Park 保存逻辑继续执行
}
```

**修改带来的功能**

未回零或位置失信时不能保存错误的 Park 坐标，避免下一次启动从错误位置恢复

---

### 7. Guide 层只锁危险方向并允许反向脱困

- **对照基准**：原始 Guide 层遇到 `ERR_LIMIT_SENSE` 时没有物理限位方向锁
- **修改文件**：`Guide.ino`
- **修改逻辑**：Axis1 与 Axis2 分别检查危险方向，并为相反方向建立脱困例外

```cpp
bool escapingPhysicalLimitAxis1 = false;

#if LIMIT_SENSE != OFF
  if (direction == 'e' && Axis1_LimitLock == 1)
    return CE_SLEW_ERR_OUTSIDE_LIMITS;

  if (direction == 'w' && Axis1_LimitLock == -1)
    return CE_SLEW_ERR_OUTSIDE_LIMITS;

  escapingPhysicalLimitAxis1 =
    generalError == ERR_LIMIT_SENSE &&
    ((direction == 'e' && Axis1_LimitLock == -1) ||
     (direction == 'w' && Axis1_LimitLock == 1));
#endif
```

```cpp
bool escapingPhysicalLimitAxis2 = false;

#if LIMIT_SENSE != OFF
  if (direction == 'n' && Axis2_LimitLock == 1)
    return CE_SLEW_ERR_OUTSIDE_LIMITS;

  if (direction == 's' && Axis2_LimitLock == -1)
    return CE_SLEW_ERR_OUTSIDE_LIMITS;

  escapingPhysicalLimitAxis2 =
    generalError == ERR_LIMIT_SENSE &&
    ((direction == 'n' && Axis2_LimitLock == -1) ||
     (direction == 's' && Axis2_LimitLock == 1));
#endif
```

**修改带来的功能**

危险方向在 Guide 底层被拒绝，串口、ST4 和其他入口都不能绕过。相反方向可以越过 `ERR_LIMIT_SENSE` 完成脱困

---

### 8. loop2() 增加物理限位方向记录与双轴逃离判断

- **对照基准**：原始 OnStep 4.24 对 LimitPin 进行两次读取，确认触发后直接调用 `SS_LIMIT`
- **修改文件**：`OnStep.ino`
- **修改逻辑**：记录当前运动方向，结合轴位置推断静止触发方向，并判断双轴是否都在远离限位

```cpp
#if LIMIT_SENSE != OFF
  byte limit_reading = digitalRead(LimitPin);
  unsigned long currentTime = millis();

  if (limit_reading == LIMIT_SENSE_STATE) {
    lastLimitTriggerTime = currentTime;

    if (isHoming()) {
      Axis1_LimitLock = 0;
      Axis2_LimitLock = 0;
      return;
    }

    delay(2);
    if (digitalRead(LimitPin) == LIMIT_SENSE_STATE) {
      int currentMotionDir1 = 0;
      int currentMotionDir2 = 0;

      if (guideDirAxis1 == 'e') currentMotionDir1 = 1;
      else if (guideDirAxis1 == 'w') currentMotionDir1 = -1;

      if (guideDirAxis2 == 'n') currentMotionDir2 = 1;
      else if (guideDirAxis2 == 's') currentMotionDir2 = -1;

      if (trackingState == TrackingMoveTo) {
        if (targetAxis1.part.m < posAxis1) currentMotionDir1 = 1;
        else if (targetAxis1.part.m > posAxis1) currentMotionDir1 = -1;

        if (targetAxis2.part.m > posAxis2) currentMotionDir2 = 1;
        else if (targetAxis2.part.m < posAxis2) currentMotionDir2 = -1;
      }
```

```cpp
      if (Axis1_LimitLock == 0) {
        if (currentMotionDir1 != 0 && trackingState == TrackingMoveTo) {
          Axis1_LimitLock = currentMotionDir1;
        } else {
          long threshold = 500L;
          if (posAxis1 > threshold) Axis1_LimitLock = -1;
          else if (posAxis1 < -threshold) Axis1_LimitLock = 1;
          else if (currentMotionDir1 != 0)
            Axis1_LimitLock = currentMotionDir1;
        }
      }

      if (Axis2_LimitLock == 0) {
        if (currentMotionDir2 != 0 && trackingState == TrackingMoveTo) {
          Axis2_LimitLock = currentMotionDir2;
        } else {
          long threshold = 500L;
          if (posAxis2 > threshold) Axis2_LimitLock = 1;
          else if (posAxis2 < -threshold) Axis2_LimitLock = -1;
          else if (currentMotionDir2 != 0)
            Axis2_LimitLock = currentMotionDir2;
        }
      }

      const bool axis1MovingIntoLimit =
        Axis1_LimitLock != 0 && currentMotionDir1 == Axis1_LimitLock;

      const bool axis2MovingIntoLimit =
        Axis2_LimitLock != 0 && currentMotionDir2 == Axis2_LimitLock;

      const bool hasEscapeMotion =
        currentMotionDir1 != 0 || currentMotionDir2 != 0;

      const bool isEscaping =
        hasEscapeMotion && !axis1MovingIntoLimit && !axis2MovingIntoLimit;

      if (!isEscaping) {
        generalError = ERR_LIMIT_SENSE;
        stopGuideAxis1();
        stopGuideAxis2();
        stopSlewingAndTracking(SS_LIMIT_PHYSICAL);
      }
    }
  } else if (currentTime - lastLimitTriggerTime > 500) {
    if (guideDirAxis1 == 0 && trackingState != TrackingMoveTo)
      Axis1_LimitLock = 0;

    if (guideDirAxis2 == 0 && trackingState != TrackingMoveTo)
      Axis2_LimitLock = 0;
  }
#endif
```

**修改带来的功能**

GOTO 与手动移动都能记录危险侧。双轴中只要仍有一轴朝限位运动就执行停止，限位释放并停稳 500 毫秒后自动清除方向锁

---

### 9. 修复客户端首次连接误报已经回零

- **对照基准**：原始 `:GU#` 只根据 `atHome` 返回 `H`
- **修改文件**：`Command.ino`
- **修改逻辑**：Home 状态必须同时满足位置可信

```cpp
if (atHome && positionReady()) reply[i++] = 'H';
```

**修改带来的功能**

上电后即使 `atHome` 保留启动值，客户端也不会收到可信 Home。只有 Find Home 或 Set Home 完成并解除恢复锁后才返回 `H`

---

### 10. 将自动回零扩展为三阶段状态机

- **对照基准**：原始 OnStep 4.24 只有快速搜索、慢速精找和完成状态
- **修改文件**：`Home.ino`
- **修改逻辑**：增加第二次停稳状态和零位偏置状态

```cpp
enum findHomeModes {
  FH_OFF,
  FH_FAST,
  FH_IDLE,
  FH_SLOW,
  FH_IDLE2,
  FH_OFFSET,
  FH_DONE
};
```

```text
FH_FAST   快速寻找 Home 开关
FH_IDLE   等待双轴停止并进入慢速精找
FH_SLOW   慢速再次寻找 Home 开关
FH_IDLE2  等待双轴停止并进入零位偏置
FH_OFFSET 按配置角度移动到真实零位
FH_DONE   重建坐标并解除恢复锁
```

**修改带来的功能**

Home 开关位置不再被直接当作最终机械零位。传感器负责提供重复定位基准，第三阶段再补偿安装偏差

---

### 11. Home 速度、超时和双轴偏置改为可配置

- **对照基准**：原始快速阶段固定 8 档并按 180 度计算超时，慢速阶段固定 7 档和 30 秒超时
- **修改文件**：`Config.h`、`Home.ino`
- **修改逻辑**：速度档位与偏置角度由配置决定，阶段超时按角度范围换算

```cpp
// Config.h
#define HOME_FAST_RATE                  9
#define HOME_SLOW_RATE                  7
#define HOME_OFFSET_AXIS1            -1.5
#define HOME_OFFSET_AXIS2               1
#define HOME_OFFSET_RATE                8
```

```cpp
// Home.ino 快速阶段
double secPerDeg = 3600.0 / (double)guideRates[HOME_FAST_RATE];
findHomeTimeout = millis() +
  (unsigned long)(secPerDeg * 360.0 * 1000.0);

e = startGuideAxis1(a1, HOME_FAST_RATE, 0, false);
if (e == CE_NONE)
  e = startGuideAxis2(a2, HOME_FAST_RATE, 0, false, true);
```

```cpp
// Home.ino 慢速阶段
double secPerDeg = 3600.0 / (double)guideRates[HOME_SLOW_RATE];
findHomeTimeout = millis() +
  (unsigned long)(secPerDeg * 6.0 * 1000.0);

e = startGuideAxis1(a1, HOME_SLOW_RATE, 0, false);
if (e == CE_NONE)
  e = startGuideAxis2(a2, HOME_SLOW_RATE, 0, false, true);
```

```cpp
// Home.ino 偏置阶段
double secPerDeg = 3600.0 / (double)guideRates[HOME_OFFSET_RATE];

char dir1 = HOME_OFFSET_AXIS1 > 0 ? 'e' : 'w';
unsigned long duration1 =
  (unsigned long)(fabs(HOME_OFFSET_AXIS1) * secPerDeg * 1000.0);

char dir2 = HOME_OFFSET_AXIS2 > 0 ? 'n' : 's';
unsigned long duration2 =
  (unsigned long)(fabs(HOME_OFFSET_AXIS2) * secPerDeg * 1000.0);
```

**修改带来的功能**

第一阶段保持约 360 度搜索余量，第二阶段保持约 6 度精找范围。修改速度后超时保护仍与机械角度对应，双轴偏置可以分别设置方向和角度

---

### 12. 回零阶段超时或启动失败时保留位置锁

- **对照基准**：原始回零失败会停止流程，但没有独立的位置可信状态需要维护
- **修改文件**：`Home.ino`
- **修改逻辑**：第一、第二、第三阶段失败都退出 Home，并确保位置仍然不可信

```cpp
if ((long)(millis() - findHomeTimeout) > 0L ||
    (guideDirAxis1 == 0 && guideDirAxis2 == 0)) {

  if ((long)(millis() - findHomeTimeout) > 0L)
    generalError = ERR_LIMIT_SENSE;

  safetyLimitsOn = true;
  invalidatePositionReference();
  gotoAbortState = GOTO_ABORT_NONE;
  findHomeMode = FH_OFF;
}
```

```cpp
if (e1 != CE_NONE || e2 != CE_NONE) {
  findHomeMode = FH_OFF;
  safetyLimitsOn = true;
  generalError = ERR_LIMIT_SENSE;
  stopSlewingAndTracking(SS_ALL_FAST);
  VLF("MSG: Homing phase 3 failed");
  return;
}
```

```cpp
if (e != CE_NONE) {
  findHomeMode = FH_OFF;
  safetyLimitsOn = true;
  stopSlewingAndTracking(SS_ALL_FAST);
}
```

**修改带来的功能**

传感器未触发、搜索超时或偏置启动失败时不会继续进入 `FH_DONE`。GOTO 与 Tracking 仍保持锁定，用户可以重新 Find Home 或人工 Set Home

---

### 13. 只有 FH_DONE 才重新建立可信位置

- **对照基准**：原始完成状态只负责设置起始位置和 `atHome`
- **修改文件**：`Home.ino`
- **修改逻辑**：完成三阶段并停稳后统一清理恢复状态和限位方向锁

```cpp
if (findHomeMode == FH_DONE &&
    guideDirAxis1 == 0 && guideDirAxis2 == 0) {

  findHomeMode = FH_OFF;

  #if AXIS2_TANGENT_ARM == ON
    trackingState = abortTrackingState;
    cli();
    targetAxis2.part.m = 0;
    targetAxis2.part.f = 0;
    posAxis2 = 0;
    sei();
  #else
    initStartPosition();
    atHome = true;
  #endif

  completePositionRecovery();
  safetyLimitsOn = true;
  abortGoto = 0;
  lastTrackingState = TrackingNone;
  abortTrackingState = TrackingNone;
  generalError = ERR_NONE;
}
```

**修改带来的功能**

只有快速搜索、慢速精找和零位偏置全部成功后才开放自动动作。完成时同时清除旧限位锁、GOTO 中断和错误状态

---

### 14. HOME_SENSE 关闭时保留坐标 Home 恢复路径

- **对照基准**：新增位置安全锁后，无传感器设备需要一条不会被 `positionReady()` 永久阻断的回零路径
- **修改文件**：`Home.ino`
- **修改逻辑**：位置仍可信但要求恢复时，只允许原生坐标 Home 使用这份坐标

```cpp
#if HOME_SENSE == OFF
  const bool homeMayOverridePark = positionHomeReturnOnly();
#else
  const bool homeMayOverridePark = !positionReady();
#endif

if (parkStatus == Parked && homeMayOverridePark) {
  parkStatus = NotParked;
  nv.write(EE_parkStatus, parkStatus);
}
```

```cpp
#if HOME_SENSE == OFF
  const bool coordinateHomeSafe =
    parkStatus == NotParked &&
    !trackingSyncInProgress() &&
    trackingState != TrackingMoveTo &&
    guideDirAxis1 == 0 && guideDirAxis2 == 0 &&
    !faultAxis1 && !faultAxis2;

  if (e == CE_SLEW_ERR_IN_STANDBY &&
      coordinateHomeSafe && positionHomeReturnOnly()) {
    enableStepperDrivers();
    e = CE_NONE;
  }
#endif
```

**修改带来的功能**

关闭 Home 传感器时，设备仍能依靠可信的开环坐标返回 Home。若位置已经完全不可信，则必须由用户把机械结构放回零位后执行 Set Home

---

### 15. Set Home 成为明确的人工恢复入口

- **对照基准**：原始 Set Home 会重建起始位置，但不需要处理新增的位置恢复状态
- **修改文件**：`Home.ino`
- **修改逻辑**：用户确认机械零位后统一恢复位置可信并清理安全残留

```cpp
CommandErrors setHome() {
  if (isSlewing()) return CE_MOUNT_IN_MOTION;

  reactivateBacklashComp();
  initStartupValues();
  initStartPosition();
  safetyLimitsOn = true;
  StepperModeTrackingInit();

  // 原始 PEC 与 Park 状态处理继续执行

  completePositionRecovery();
  abortGoto = 0;
  generalError = ERR_NONE;
  return CE_NONE;
}
```

**修改带来的功能**

有无 Home 传感器都可以通过 Set Home 人工确认机械位置。该命令会解除位置恢复锁，但不会自动寻找零位，执行前必须由用户确认姿态正确

---

### 16. 坐标 Home 被中断时不解除恢复状态

- **对照基准**：原始 `MoveTo.ino` 在坐标 Home 结束后恢复 Tracking 并设置 `atHome`
- **修改文件**：`MoveTo.ino`
- **修改逻辑**：先检查 Home 运动是否被安全状态中断，再决定是否完成恢复

```cpp
if (homeMount) {
  const GotoAbortState completedHomeState = gotoAbortState;

  if (completedHomeState != GOTO_ABORT_NONE) {
    homeMount = false;
    trackingSyncSeconds = 0;
    trackingState = TrackingNone;
    lastTrackingState = TrackingNone;
    gotoAbortState = GOTO_ABORT_NONE;
    gotoStartTrackingOnSuccess = false;
    SiderealClockSetInterval(siderealInterval);
    setDeltaTrackingRate();
  } else {
    if (parkClearBacklash() == -1) return;
    soundAlert();
    trackingState = lastTrackingState;
    lastTrackingState = TrackingNone;
    SiderealClockSetInterval(siderealInterval);
    homeMount = false;
    if (AXIS2_TANGENT_ARM == OFF) atHome = true;
    completePositionRecovery();
    safetyLimitsOn = true;
  }
}
```

**修改带来的功能**

无传感器坐标 Home 只有正常完成时才恢复位置可信。被限位或其他安全状态中断时保持 Tracking 关闭，并继续要求用户恢复位置

---

### 17. GOTO 完成时按中断类型分别收尾

- **对照基准**：原始 `MoveTo.ino` 在 GOTO 结束后统一恢复 `lastTrackingState` 并报告完成
- **修改文件**：`Goto.ino`、`MoveTo.ino`
- **修改逻辑**：启动前记录一次性 Tracking 请求，结束后按正常完成、普通停止、物理停止和位置丢失分别处理

```cpp
// Goto.ino
const bool requestTrackingAfterSuccess =
  trackingState == TrackingNone &&
  timeWasSet && dateWasSet &&
  positionReady() &&
  parkStatus == NotParked &&
  !isHoming();

CommandErrors result =
  goTo(Axis1, Axis2, Axis1Alt, Axis2Alt, thisPierSide);

if (result == CE_NONE)
  gotoStartTrackingOnSuccess = requestTrackingAfterSuccess;
```

```cpp
// MoveTo.ino
if (completedGotoState == GOTO_ABORT_POSITION_LOST ||
    !positionReady()) {

  trackingState = TrackingNone;
  lastTrackingState = TrackingNone;
  if (generalError == ERR_NONE) generalError = ERR_LIMIT_SENSE;

} else if (completedGotoState == GOTO_ABORT_HARD_STOP) {

  trackingState = TrackingNone;
  lastTrackingState = TrackingNone;

} else {

  trackingState = lastTrackingState;
  lastTrackingState = TrackingNone;

  if (completedGotoState == GOTO_ABORT_NONE && startTracking)
    trackingState = TrackingSidereal;

  if (completedGotoState == GOTO_ABORT_NONE &&
      trackingState == TrackingSidereal) {
    trackingSyncSeconds = 5;
  }
}

gotoAbortState = GOTO_ABORT_NONE;
gotoStartTrackingOnSuccess = false;
```

**修改带来的功能**

安全中断不会再走正常 GOTO done 流程。只有正常到达才允许自动 Tracking 和 5 秒坐标同步窗口，避免出现失败 GOTO 后的幽灵 Tracking

---

### 18. stopSlewingAndTracking() 标记安全中断等级

- **对照基准**：原始函数只负责停止对应运动，没有位置恢复等级
- **修改文件**：`OnStep.ino`
- **修改逻辑**：驱动故障、物理限位和普通软件停止分别写入不同的 GOTO 中断类型

```cpp
if (ss == SS_LIMIT_HARD) {
  invalidatePositionReference();
  safetyLimitsOn = false;

  if (trackingState == TrackingMoveTo)
    gotoAbortState = GOTO_ABORT_POSITION_LOST;
}

if (ss == SS_LIMIT_PHYSICAL) {
  gotoStartTrackingOnSuccess = false;

#if HOME_REQUIRED_AFTER_LIMIT == ON
  #if HOME_SENSE == OFF
    requireCoordinateHomeRecovery();
  #else
    invalidatePositionReference();
  #endif

  safetyLimitsOn = false;
  if (trackingState == TrackingMoveTo)
    gotoAbortState = GOTO_ABORT_POSITION_LOST;
#else
  if (trackingState == TrackingMoveTo)
    gotoAbortState = GOTO_ABORT_HARD_STOP;
#endif
}

if (trackingState == TrackingMoveTo) {
  gotoStartTrackingOnSuccess = false;

  if (ss != SS_ALL_FAST && gotoAbortState == GOTO_ABORT_NONE)
    gotoAbortState = GOTO_ABORT_STOPPED;

  if (!abortGoto) abortGoto = StartAbortGoto;
}
```

**修改带来的功能**

更严重的位置丢失状态不会被后续普通停止覆盖。`HOME_REQUIRED_AFTER_LIMIT` 可以决定物理限位后是否强制重新 Home

---

### 19. 标记 MaxESP3 共享模式引脚并增加编译校验

- **对照基准**：原始 MaxESP3 定义了相同的 M0 与 M1 引脚，但没有声明独立模式驱动器需要双轴同步切换
- **修改文件**：`src/pinmaps/Pins.MaxESP3.h`、`src/pinmaps/Validate.MaxESP3.h`、`Validate.h`、`src/sd_drivers/Validate.TMC2209.h`
- **修改逻辑**：调整当前控制板引脚，显式标记共享模式引脚，并要求 TMC2209 双轴配置一致

```cpp
// Pins.MaxESP3.h 当前控制板引脚
#define Aux2                  2
#define Aux3                 21
#define Aux4                 22
#define Aux5                 25
#define Aux6                 15
#define Aux7                 39
#define Aux8                 12

#define PpsPin               36
#define LimitPin           Aux7

#define Axis1_EN              4
#define Axis1_STEP           18
#define Axis1_DIR            19
#define Axis1_HOME         Aux5

#define Axis2_EN         SHARED
#define Axis2_STEP           27
#define Axis2_DIR            26
#define Axis2_HOME         Aux6
```

```cpp
// Pins.MaxESP3.h
#define Axis1_M0 13
#define Axis1_M1 14
#define Axis2_M0 13
#define Axis2_M1 14

#define AXIS12_DRIVER_MODE_PINS_SHARED
```

```cpp
// Validate.h
#if defined(AXIS12_DRIVER_MODE_PINS_SHARED) && \
    (AXIS1_DRIVER_MODEL == TMC2209 || AXIS2_DRIVER_MODEL == TMC2209)

  #if AXIS1_DRIVER_MODEL != TMC2209 || AXIS2_DRIVER_MODEL != TMC2209
    #error "Configuration (Config.h): shared M0/M1 pins require TMC2209 on both Axis1 and Axis2."
  #endif

  #if AXIS1_DRIVER_MICROSTEPS != AXIS2_DRIVER_MICROSTEPS
    #error "Configuration (Config.h): shared TMC2209 M0/M1 pins require equal Axis1/Axis2 tracking microsteps."
  #endif

  #if AXIS1_DRIVER_MICROSTEPS_GOTO != AXIS2_DRIVER_MICROSTEPS_GOTO
    #error "Configuration (Config.h): shared TMC2209 M0/M1 pins require equal Axis1/Axis2 Goto microsteps."
  #endif

  #if MODE_SWITCH_BEFORE_SLEW != OFF
    #error "Configuration (Config.h): shared TMC2209 M0/M1 pins require on-the-fly mode switching."
  #endif

  #define AXIS12_TMC2209_MODE_SHARED
#endif
```

**修改带来的功能**

Home、Limit、PPS、Axis1 Enable 和 Axis1 Dir 已按当前控制板重新分配。对应的引脚占用检查也同步修改。双轴驱动型号和细分不一致时会在编译阶段报错，避免生成可以启动但运动比例错误的固件。当前仓库默认驱动仍为 `TMC5160_QUIET`，TMC2209 共享逻辑需要按实际硬件启用

---

### 20. MaxESP3 TMC2209 双轴同步切换细分

- **对照基准**：原始 Timer 逻辑分别判断 Axis1 与 Axis2 的 GOTO 模式，并在两个电机中断中独立切换
- **修改文件**：`Timer.ino`、`StepMode.ino`
- **修改逻辑**：任一轴需要 GOTO 细分时双轴共同进入 GOTO 模式，切换前等待两个轴都处于可表示位置

```cpp
// Timer.ino
gotoRateAxis1 =
  thisTimerRateAxis1 < AXIS1_DRIVER_SWITCH_RATE ||
  thisTimerRateAxis2 < AXIS2_DRIVER_SWITCH_RATE;

gotoRateAxis2 = gotoRateAxis1;
```

```cpp
bool axis1Ready =
  (!inbacklashAxis1 && posAxis1 == (long)targetAxis1.part.m) ||
  ((posAxis1 + blAxis1) % axis1StepsGoto == 0);

bool axis2Ready =
  (!inbacklashAxis2 && posAxis2 == (long)targetAxis2.part.m) ||
  ((posAxis2 + blAxis2) % axis2StepsGoto == 0);

if (!axis1Ready || !axis2Ready) return;

a1CLEAR;
a2CLEAR;

if (gotoRateAxis1) {
  axis1DriverGotoFast();
  gotoModeAxis1 = true;
  gotoModeAxis2 = true;
} else {
  axis1DriverTrackingFast();
  gotoModeAxis1 = false;
  gotoModeAxis2 = false;
}
```

```cpp
// StepMode.ino
#ifdef AXIS12_TMC2209_MODE_SHARED
  stepAxis1 = axis1StepsGoto;
  stepAxis2 = axis2StepsGoto;
#endif
```

**修改带来的功能**

一个轴先减速时不会单独改变另一个轴的硬件细分。双轴硬件模式与软件步距保持一致，MaxESP3 独立模式 TMC2209 可以使用 64 细分跟踪和 32 细分 GOTO

---

## 🔁 运行状态流程 (Runtime Flow)

### 正常开机流程

```text
上电
  ↓
MOTOR_HOLD_ON_BOOT 使能双轴驱动器
  ↓
Tracking 保持关闭
  ↓
HOME_REQUIRED_ON_BOOT 要求位置确认
  ↓
手动方向键仍可移动
  ↓
GOTO、Sync、Park 和 Tracking 被锁定
  ↓
执行 Find Home 或人工确认后的 Set Home
  ↓
positionReady() 返回 true
  ↓
开放自动指向与跟踪
```

### 自动 Find Home 流程

```text
客户端 Find Home
或 ST4 East 与 West 长按 3 秒
  ↓
FH_FAST 快速寻找 Home 开关
  ↓
FH_IDLE 等待双轴停止
  ↓
FH_SLOW 慢速精找 Home 开关
  ↓
FH_IDLE2 等待双轴停止
  ↓
FH_OFFSET 执行双轴零位偏置
  ↓
FH_DONE 重建起始坐标
  ↓
completePositionRecovery()
  ↓
允许 GOTO 与 Tracking
```

### 限位触发流程

```text
LimitPin 稳定触发
  ↓
读取手动方向或 GOTO 目标方向
  ↓
记录 Axis1_LimitLock 与 Axis2_LimitLock
  ↓
判断双轴是否都在远离限位
  ↓
仍有轴朝危险方向运动
  ↓
停止 Guide、GOTO 与 Tracking
  ↓
根据 HOME_REQUIRED_AFTER_LIMIT 标记位置恢复要求
  ↓
允许相反方向手动脱困
  ↓
Find Home 或 Set Home 后恢复自动动作
```

---

## ✅ 当前代码行为总表

| 功能场景 | 当前行为 |
| --- | --- |
| 开机 | 双轴电机保持，Tracking 关闭，不自动建立 Home |
| 未 Home 前手动移动 | 允许 |
| 未 Home 前 GOTO 与 Sync | 返回 standby |
| 未 Home 前开启 Tracking | 立即返回失败 |
| 未 Home 前保存 Park | 拒绝 |
| 客户端首次连接 | 只有位置可信时才报告 `H` |
| ST4 East 与 West 长按 3 秒 | 启动快速 Find Home |
| 第一阶段 Home | 按配置速度搜索约 360 度范围 |
| 第二阶段 Home | 按配置速度精找约 6 度范围 |
| 第三阶段 Home | 按双轴角度和速度执行零位偏置 |
| Home 任一阶段失败 | 停止流程并保留位置恢复锁 |
| Home 完成 | 重建坐标并开放自动动作 |
| Set Home | 人工确认当前位置为机械零位并恢复位置可信 |
| HOME_SENSE 关闭 | 可信坐标可用于返回 Home，完全失信时需要 Set Home |
| 物理限位触发 | 记录危险方向并停止危险运动 |
| 限位后继续向危险侧移动 | 拒绝 |
| 限位后向相反方向移动 | 允许脱困 |
| 限位释放并停稳 500 毫秒 | 清除方向锁 |
| 驱动器硬故障 | 位置标记为不可信并停止运动 |
| GOTO 普通停止 | 不报告正常到达，不启动新的 Tracking |
| GOTO 位置丢失 | Tracking 关闭并要求 Home 或 Set Home |
| MaxESP3 TMC2209 共享细分 | 双轴同步切换硬件模式和软件步距 |

---

## 💡 总结与建议

修改之后的固件相对原始 OnStep 4.24 的重点不是增加更多自动动作，而是让每个自动动作都建立在可信位置上

- 开机只保持电机，不默认相信坐标
- GOTO、Sync、Park 和 Tracking 共用位置安全检查
- 手动方向保留，便于找零和处理机械风险
- 限位后只锁危险方向，允许反向脱困
- Home 失败不会误报成功
- GOTO 安全中断不会恢复成正常到达
- MaxESP3 TMC2209 共享细分由双轴同步处理

当前仓库带有一套具体硬件配置

```text
PINMAP                    MaxESP3
MOUNT_TYPE                GEM
TIME_LOCATION_SOURCE      DS3231
AXIS1_DRIVER_MODEL        TMC5160_QUIET
AXIS2_DRIVER_MODEL        TMC5160_QUIET
AXIS1_DRIVER_MICROSTEPS   64
AXIS2_DRIVER_MICROSTEPS   64
AXIS1_DRIVER_MICROSTEPS_GOTO 32
AXIS2_DRIVER_MICROSTEPS_GOTO 32
SLEW_RATE_BASE_DESIRED    6.0 度每秒
AXIS1_LIMIT               -180 到 180 度
AXIS2_LIMIT               -90 到 90 度
```

这套配置只适用于当前设备。刷写前应重新确认每度步数、驱动电流、电机方向、Home 极性、Limit 极性、回零偏置、软件范围和 MaxESP3 引脚。尤其不要把当前 Axis1 的正负 180 度直接视为其他赤道仪的安全范围

推荐第一次测试时卸下镜筒或保持可随时断电，先低速验证双轴方向，再验证 Home 和 Limit。回零期间普通 `LimitPin` 处理会让位于 Home 状态机，因此传感器极性、回零方向和机械余量必须在正式使用前确认

触发限位后先向相反方向手动脱困，再执行 Find Home。只有在人工确认赤道仪已经位于定义的机械零位时才使用 Set Home

固件继续使用 OnStep 的 LX200 派生命令集，可以配合 OnStep App、ASCOM、N.I.N.A、Stellarium、SkySafari、INDI 和其他兼容客户端使用

感谢 Howard Dutton 和 OnStep 社区维护原始项目。本地固件是 OnStep 4.24 的衍生版本，继续遵循 GNU General Public License，许可说明见 [LICENSE.txt](https://github.com/Leo-John233/DIY-HarmonicEquatorialMount/blob/main/software/OnStep4.24-Modified/LICENSE.txt)

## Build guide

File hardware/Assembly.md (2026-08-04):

<div align="center">
  
  
</div>

# 双25-100谐波赤道仪组装说明书

结合 `images/Assembly process` 目录下的实拍记录，分步讲解从机械结构到电控系统的完整拼装过程

## 🛠️ 准备工作与物料清单 (BOM)

在开始组装之前，请确保您已备齐以下核心零部件与工具(具体所需五金参考bom表)：

* **传动核心**：25-100型谐波减速器（1:100减速比）
* **惰轮**：2GT带宽10mm 80齿惰轮和2GT带宽10mm高19mm 20齿惰轮
* **电机与保护**：步进电机、掉电刹车（电磁阻尼/抱闸）模块
* **主控与驱动**：ESP32 + ESP07S 组合、TMC5160 步进电机驱动模块
* **电路底板**：定制设计的主控 PCB（支持 12V/24V 电源）
* **线材与辅料**：**电源开关引线**、各型号内六角螺丝、润滑脂、螺丝胶
*注：惰轮部分需要您有一定机加工能力对成品惰轮按照图纸中的规格进行改造，若无法改造，请自行修改模型以适配市面上的标准零件*
---

## 🖨️ 阶段一：3D打印与机加工准备
在正式组装之前，建议先完成以下准备工作：
1. **3D打印**：使用PETG—GF/CF材料打印所有需要的零件，确保打印质量和尺寸精度，特别是减速器保护罩，传动轴，传感器安装座等关键部件。

      **打印件清单：**
   
    | 序号 | 零件部位 | 对应源文件 |
    | :---: | :--- | :--- |
    | 1 | 主外壳 | `外壳.SLDPRT` |
    | 2 | 鸠尾槽外壳 | `鸠尾槽外壳.SLDPRT` |
    | 3 | 赤纬 / 赤经轴 | `DEC轴.SLDPRT` , `RA轴.SLDPRT` |
    | 4 | 鸠尾槽外壳 | `鸠尾槽外壳.SLDPRT` |
    | 5 | 控制板盖板 | `控制板盖板-插件.SLDPRT` |
    | 6 | 光电传感器固定座 | `光电传感器固定座A.SLDPRT`，`光电传感器固定座B.SLDPRT`，`光电传感器固定座B - 增高.SLDPRT` |

> 📷 *参考图片：*
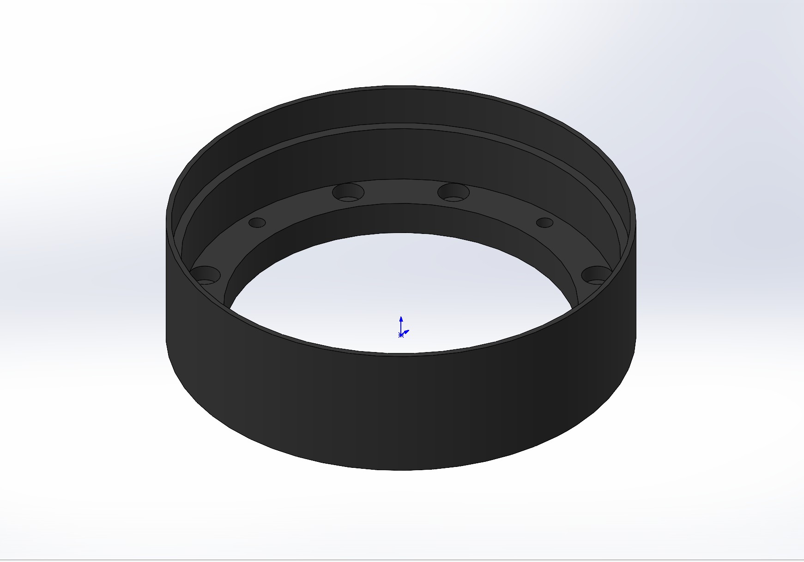
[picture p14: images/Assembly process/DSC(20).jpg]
> 
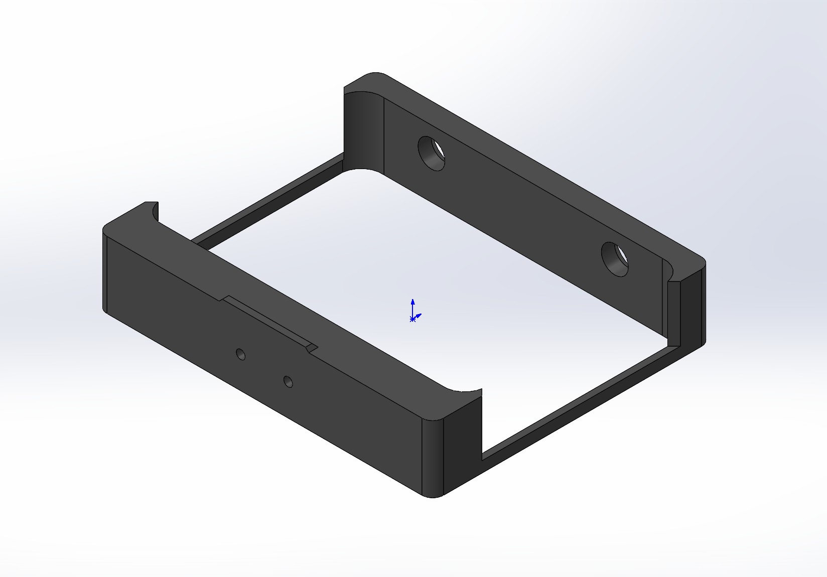
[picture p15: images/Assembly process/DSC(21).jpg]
> 
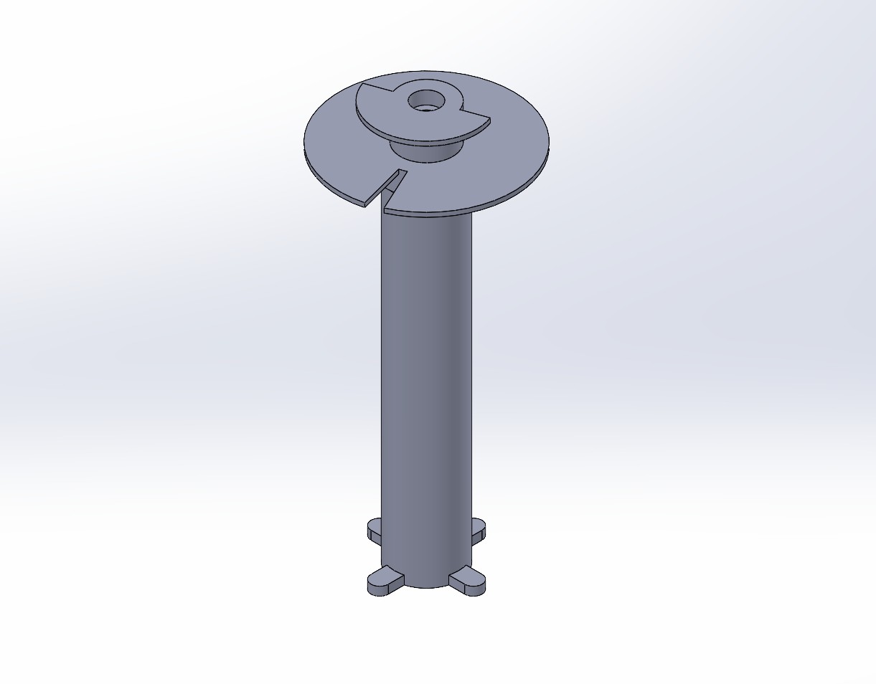
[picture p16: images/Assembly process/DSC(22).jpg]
> 

2. **给打印件熔入热熔螺母**：在组装前，先将准备好的热熔螺母熔入所有需要安装螺丝的3D打印件中，需要安装螺母的部位请参考下图中的标注，确保每个螺母都能牢固地固定在打印件中，并且位置准确，以便后续组装时能够顺利安装螺丝。

> 📷 *参考图片：*
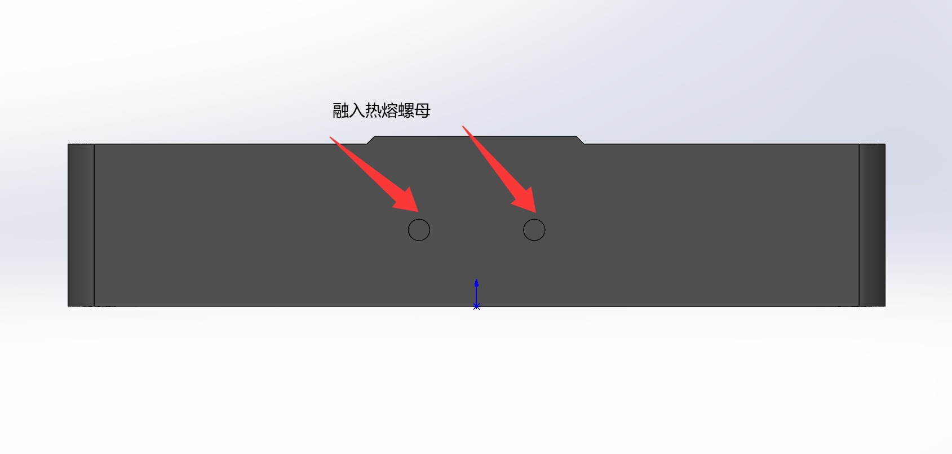
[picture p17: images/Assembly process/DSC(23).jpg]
> 
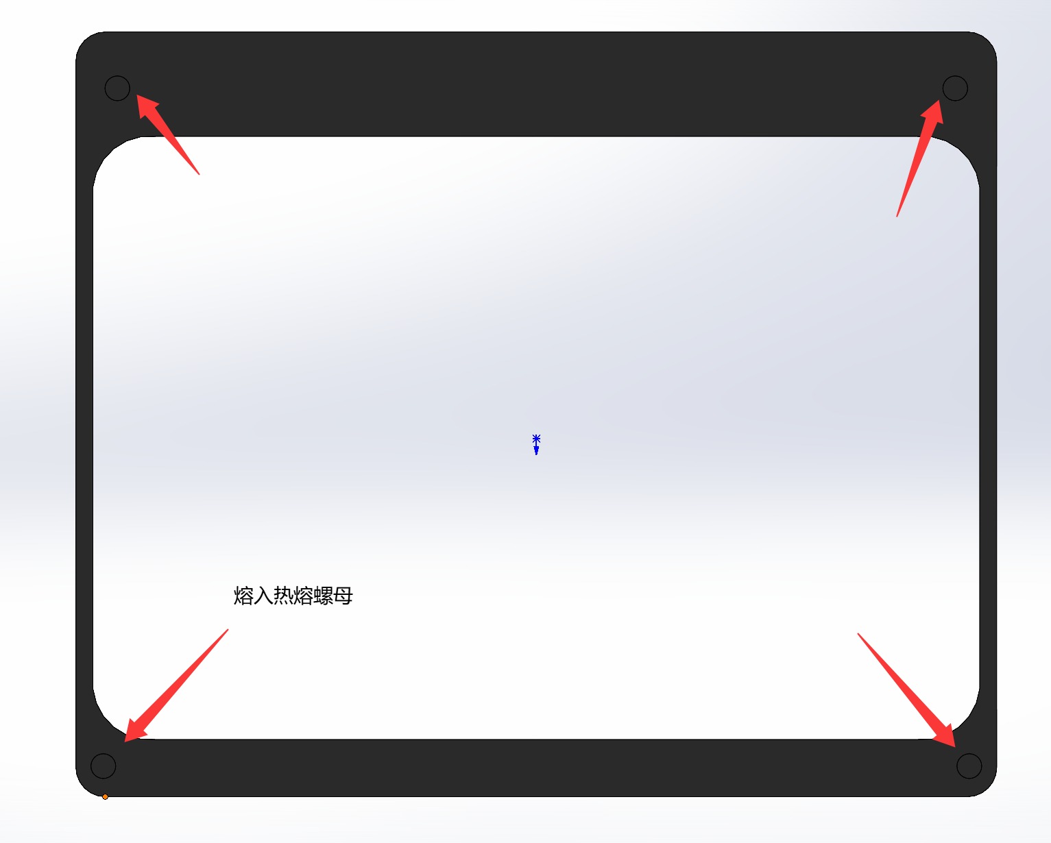
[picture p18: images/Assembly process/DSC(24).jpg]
> 
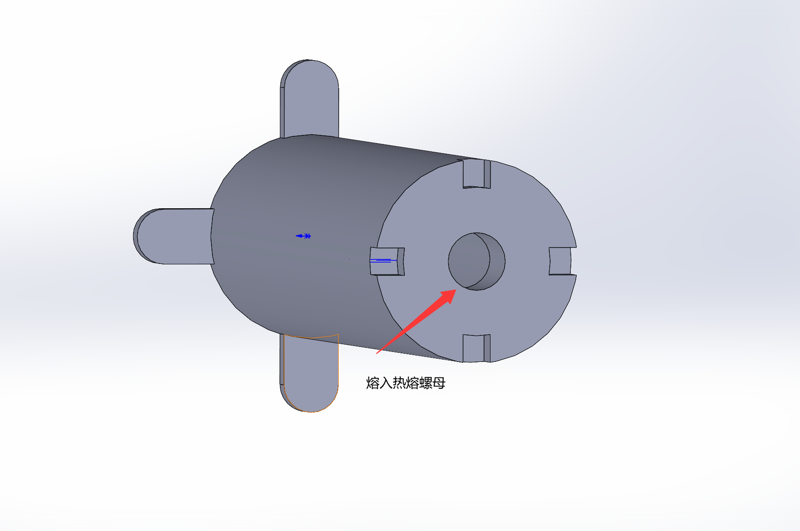
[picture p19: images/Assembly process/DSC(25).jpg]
> 
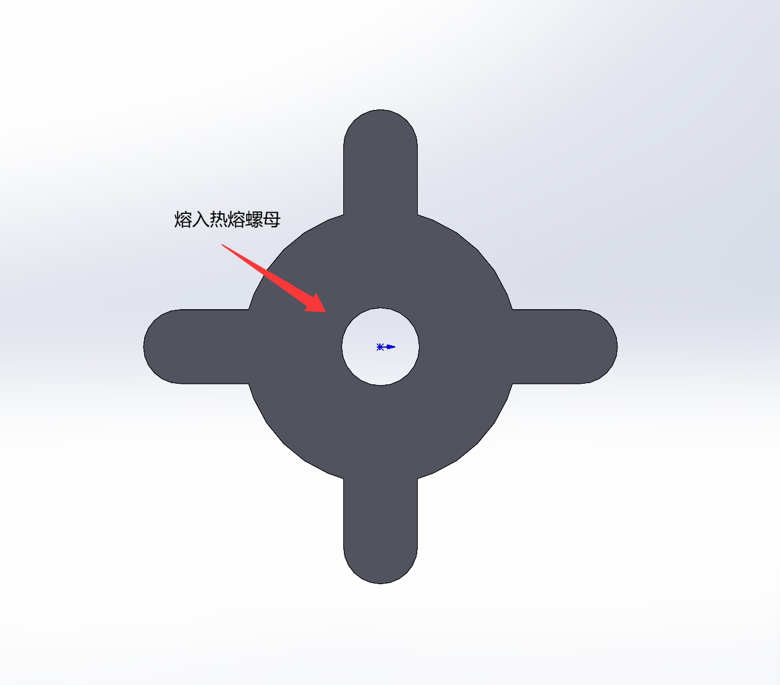
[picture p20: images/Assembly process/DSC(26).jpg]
> 

3. **机加工**：对惰轮进行必要的改造，确保其尺寸和安装孔位符合设计要求，同时对铝板进行钻孔和攻丝，准备好安装所需的螺丝和铜柱。

---

## ⚙️ 阶段二：机械结构组装

### 1. 谐波减速器的安装 (RA/DEC 轴)
在此步骤中，我们将安装赤道仪的核心部件，考虑到径向慢速旋转载荷的受力要求，安装时请务必保证法兰接触面的平整贴合

1.  将减速器法兰面与铝板螺孔精准对齐，尽可能的让铝板中心圆通孔与减速器中空轴同轴心，使用内六角螺丝并按对角线顺序均匀拧紧，确保减速器外壳受力均匀，避免因局部过紧导致的变形或过松引起的振动
2.  其中两个螺孔需要拧入更长的螺丝，且不需要拧上防松螺母以便后续电机座的安装
3.  其中有4个螺孔不需要拧入螺丝，以便后续安装3d打印的减速器保护罩
4.  将除去步骤2中的剩余的核心螺丝组件多余的部分拧入防松螺母，确保减速器与铝板之间的连接牢固且不会因振动而松动

> 📷 *参考图片：*
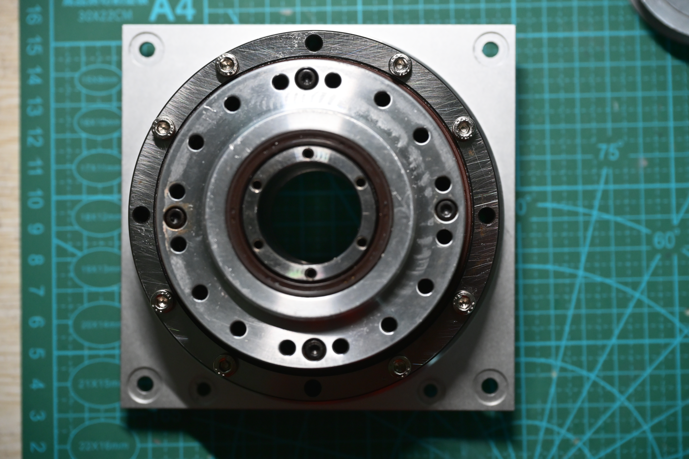
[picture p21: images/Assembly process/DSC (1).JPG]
> 
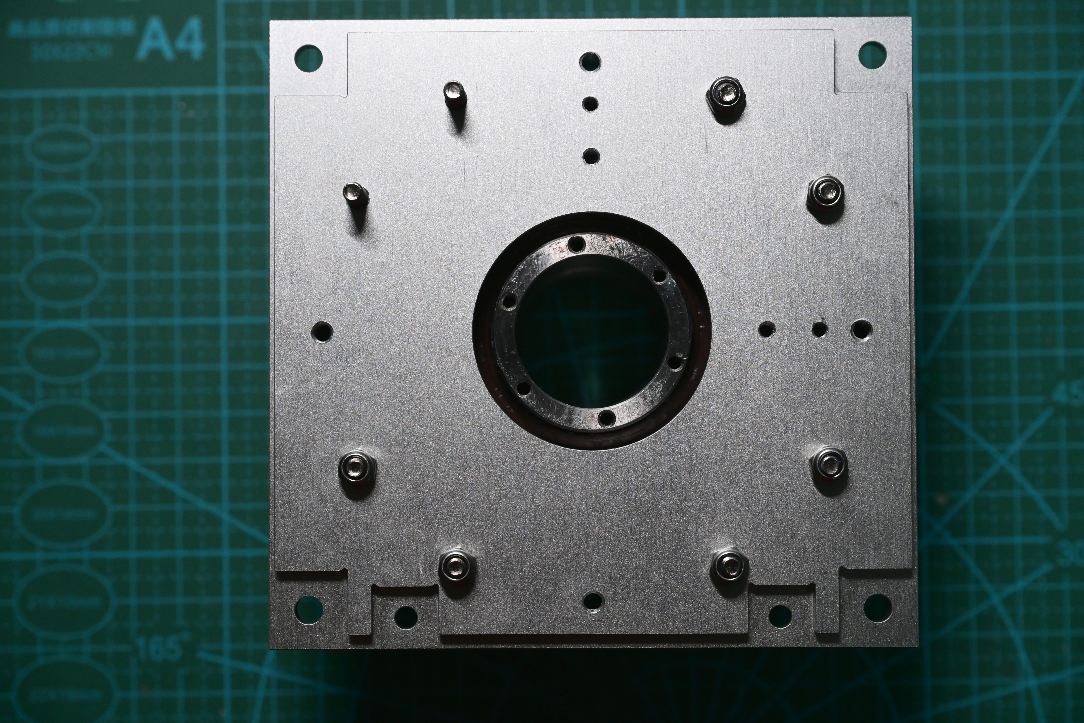
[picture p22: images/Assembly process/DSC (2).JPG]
> 
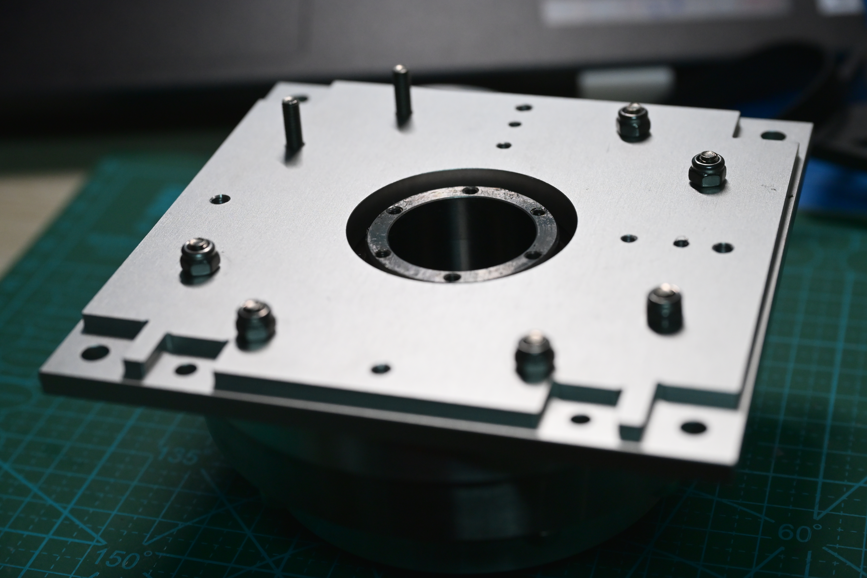
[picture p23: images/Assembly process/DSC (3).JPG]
> 

### 2. 传动部分的组合
1.  将加工过的80齿轮2GT惰轮安装在减速器的输入轴上，确保惰轮与输入轴同轴心，使用内六角螺丝并按对角线顺序均匀拧紧，确保连接牢固且不会因振动而松动
2.  将20齿轮2GT惰轮安装在步进电机的输出轴上  
3.  将步进电机通过铜柱安装至电机座上
4.  **掉电刹车安装**：在用于RA轴的双出轴步进电机的尾端，替换原有电机的螺丝并安装电磁抱闸模块，能有效防止设备意外断电时由于重锤失衡导致的望远镜“磕头”受损
5.  提前将2GT带宽10mm同步带套在电机惰轮上，便于后续安装

> 📷 *参考图片：*
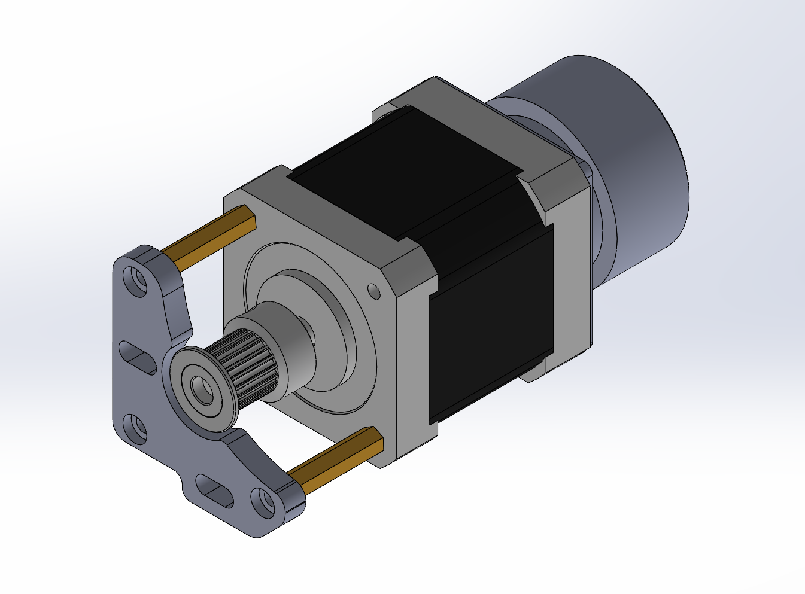
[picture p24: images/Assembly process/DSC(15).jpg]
> 
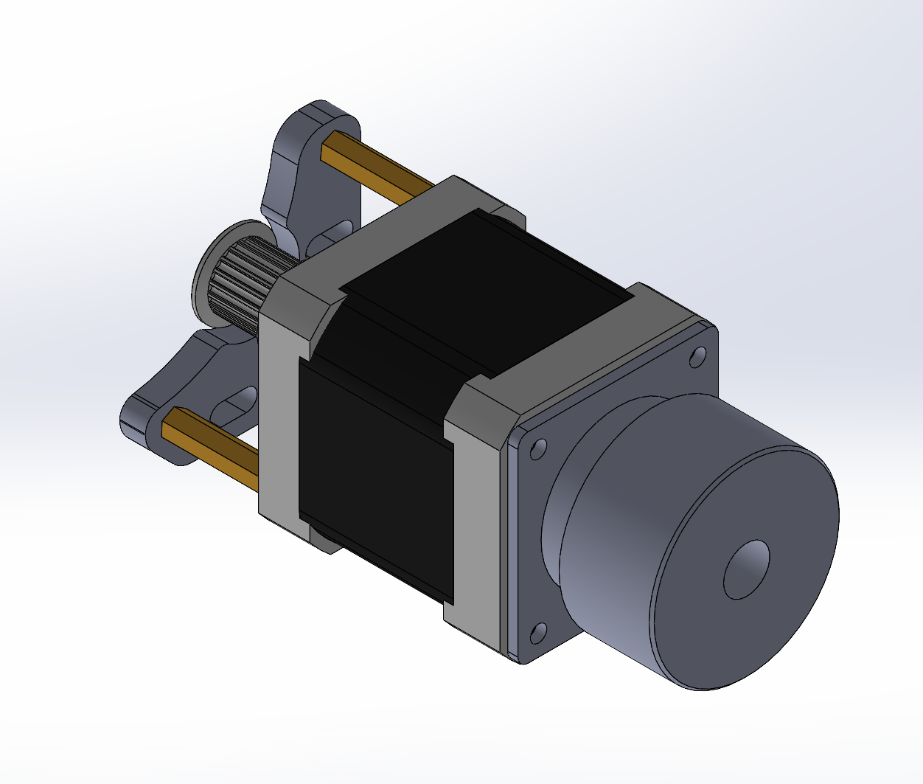
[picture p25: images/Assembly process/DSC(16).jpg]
> 
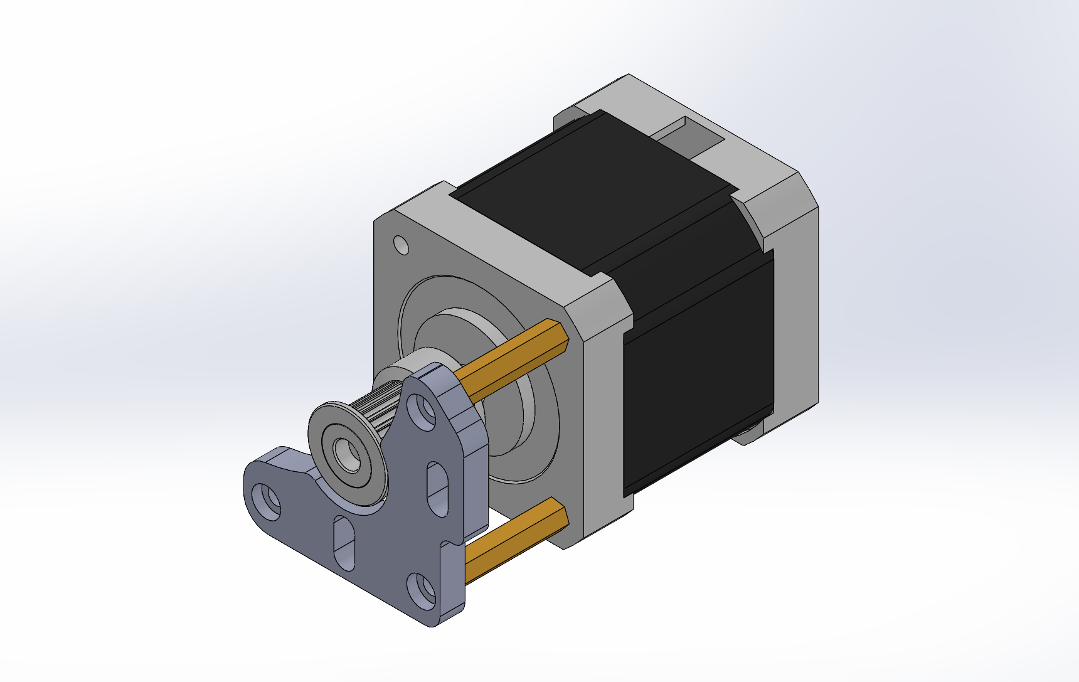
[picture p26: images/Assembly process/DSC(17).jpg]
DEC轴电机安装
> 

### 3. RA轴纬度座法兰的组装
1.  将RA轴法兰盘与连接轴A和连接轴B通过内六角螺丝连接
2.  在步骤1的过程中，同时组装推杆和推块结构，确保推杆能够在推块内顺畅滑动，并且连接轴A和连接轴B能够通过推杆实现相对运动
3.  将步骤1和2中组装好的整体结构通过内六角螺丝安装到谐波减速器的法兰盘上，在安装过程同时安装3d打印好减速器保护罩

> 📷 *参考图片：*
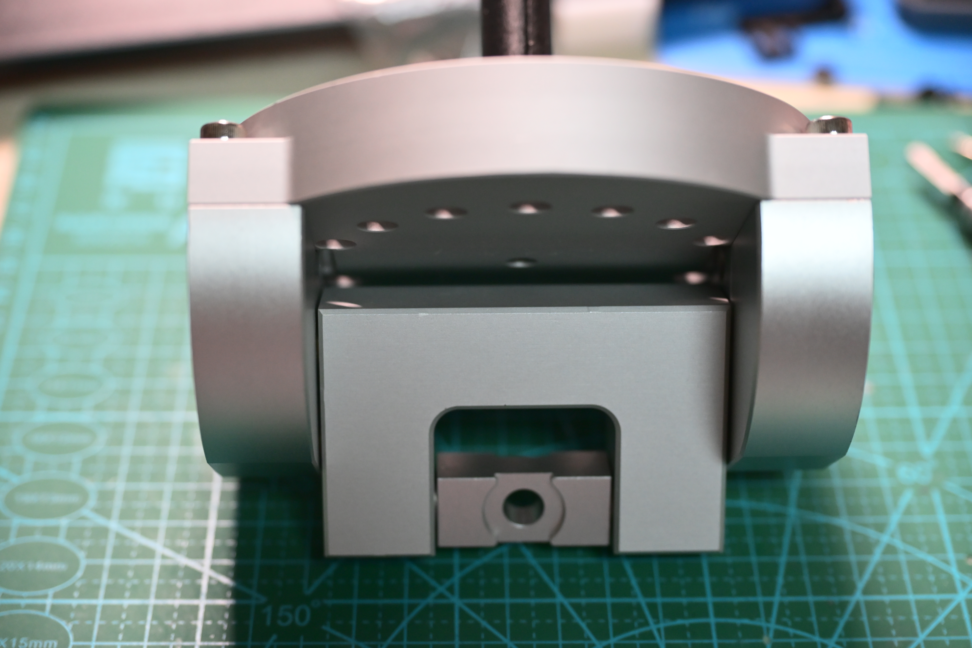
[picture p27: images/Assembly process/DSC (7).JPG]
> 
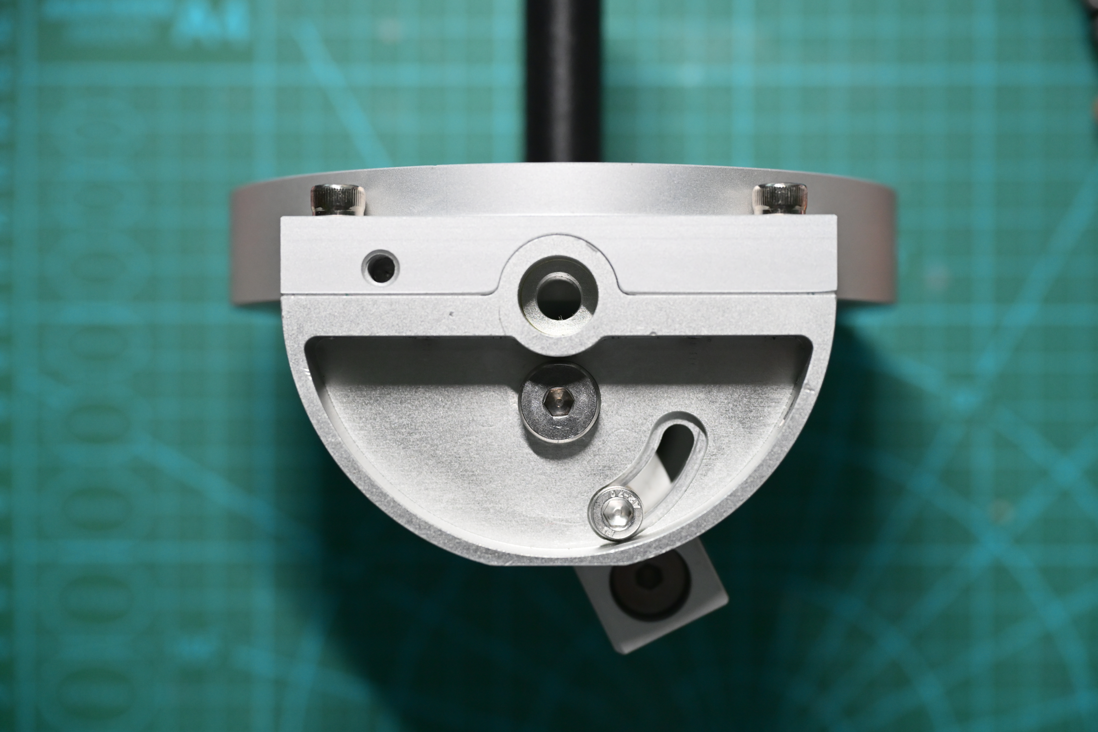
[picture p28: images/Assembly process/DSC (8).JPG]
> 
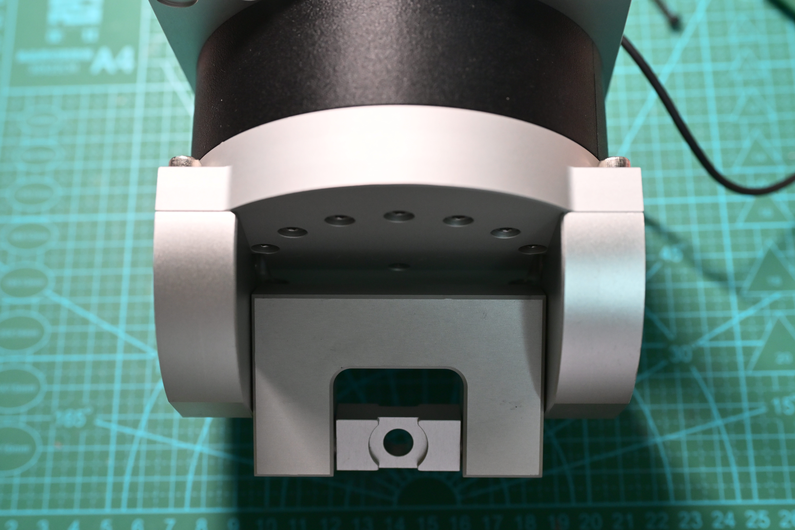
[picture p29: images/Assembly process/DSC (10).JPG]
> 

### 4. 光电传感器和电机的接线顺序
1.  确定购买的光电传感器的型号是槽型形光电开关四线制NPN型，确保其输出信号能够与 ESP32 主控板的输入引脚兼容
2.  将零位传感器(HOME传感器)的接线配置为：棕色线接+5V电源，蓝色线接GND，黑色线(即NPN NO)
3.  将限位传感器(LIMIT传感器)的接线配置为：棕色线接+5V电源，蓝色线接GND，白色线(即NPN NC)
4.  将DEC和RA轴对应电机的接线顺序为：A-，A+，B+，B-，确保电机的相序正确

### 5. 电机，同步带与减速器的连接以及传感器，法兰盘的安装
1.  通过电机座上预留的孔位安装至步骤1中铝板上预留的更长螺丝上，绷紧同步带，并在螺丝上拧上防松螺母，确保同步带在传动过程中不会发生打滑或过度松弛
2.  并适当调整电机输出轴上的惰轮高度，使其与减速器输入轴上的惰轮处于同一水平面，确保同步带的张力均匀分布，避免因不平行导致的过度磨损或传动效率降低
3.  在完成上述步骤后，手动旋转大惰轮，检查同步带的运行是否平稳，确保没有异常的摩擦声或振动，这将有助于确认传动系统的正确安装和调整
4.  在完成安装后，建议在同步带上喷涂适量的矽质润滑剂，以减少摩擦和异响并延长同步带的使用寿命
5.  安装RA/DEC轴的光电传感器限位开关和原点开关，确保它们的位置能够准确检测到轴的极限位置和原点位置，以实现安全保护和精准定位
6.  将3d打印好的减速器保护罩安装在减速器外部，使用预留的螺孔和内六角螺丝固定，确保保护罩能够有效防止灰尘和杂物进入减速器，同时不干扰其正常运行
7.  安装RA/DEC轴的法兰盘，确保其与轴同轴心，并使用内六角螺丝均匀拧紧，确保法兰盘在运行过程中不会发生偏移或松动

> 📷 *参考图片：*
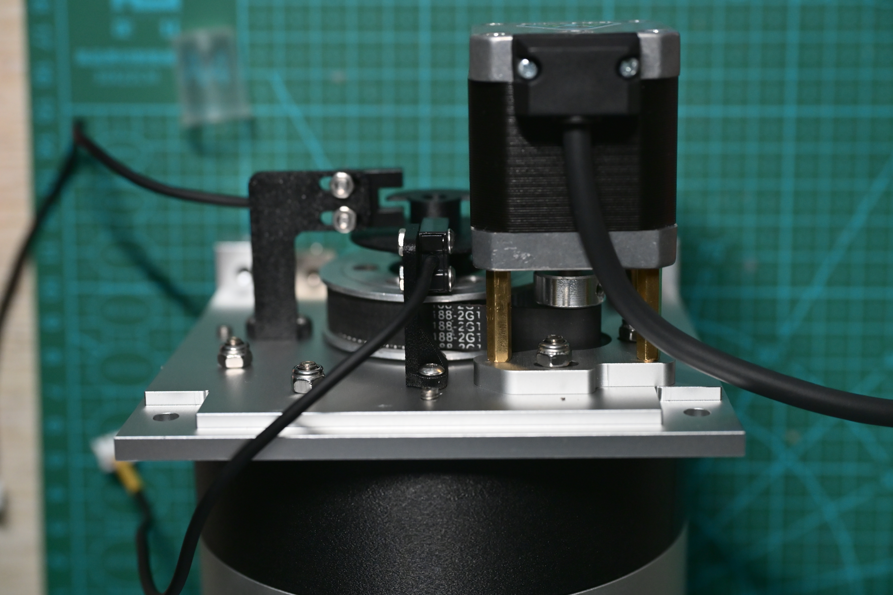
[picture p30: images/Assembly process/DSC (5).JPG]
RA轴电机与刹车模块，传感器，法兰盘的安装
> 
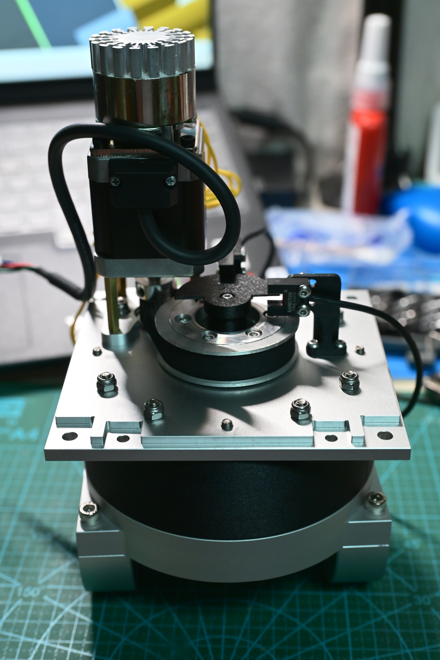
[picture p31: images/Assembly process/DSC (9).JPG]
DEC轴电机，同步带
> 
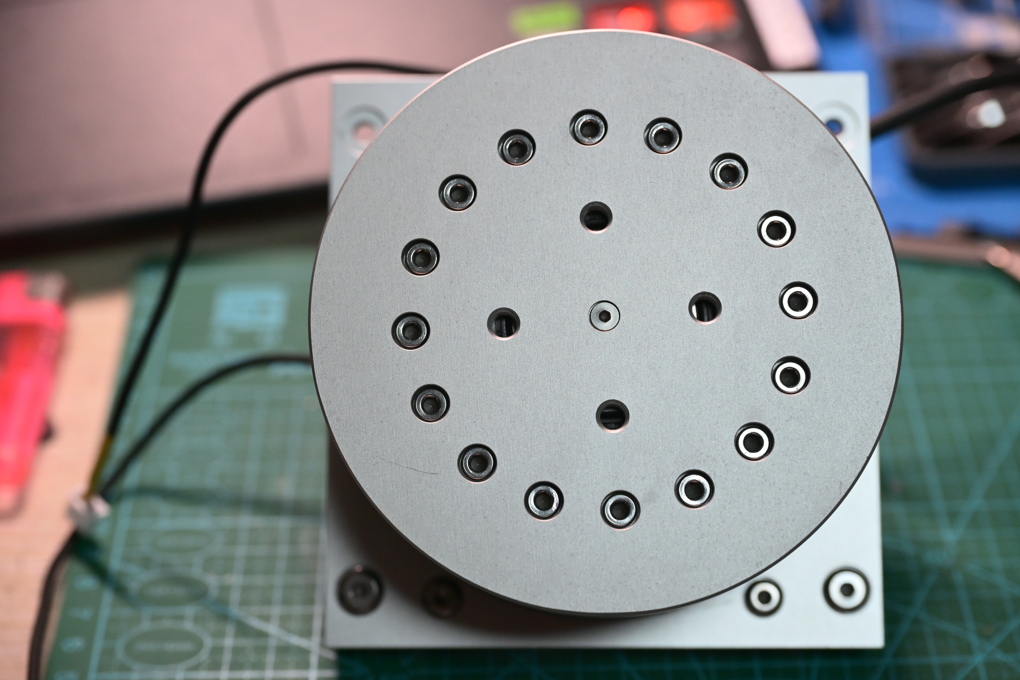
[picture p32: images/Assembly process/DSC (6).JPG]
DEC轴法兰盘的安装
> 
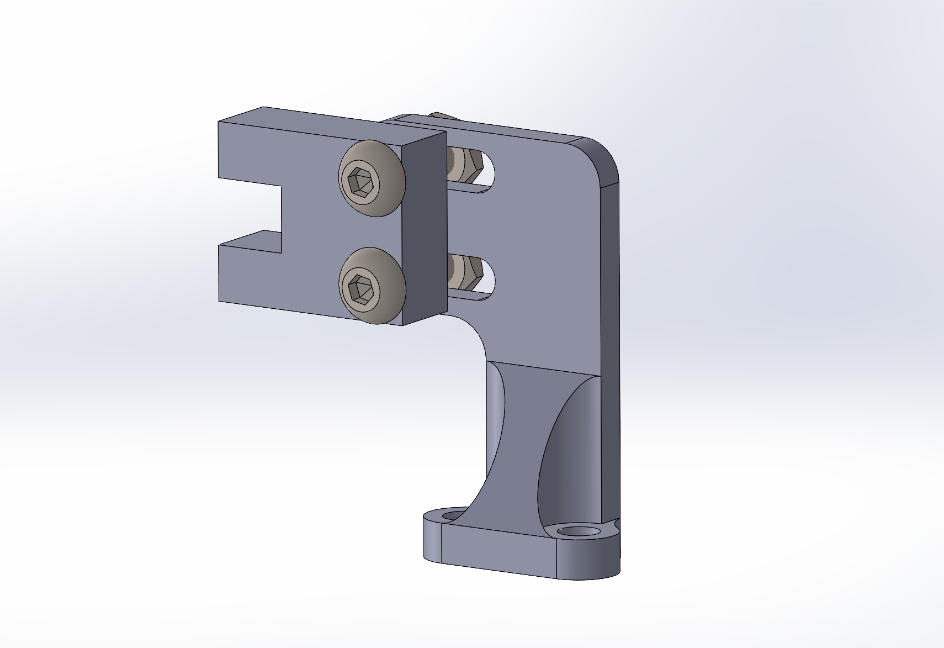
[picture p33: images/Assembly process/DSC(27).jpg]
> 
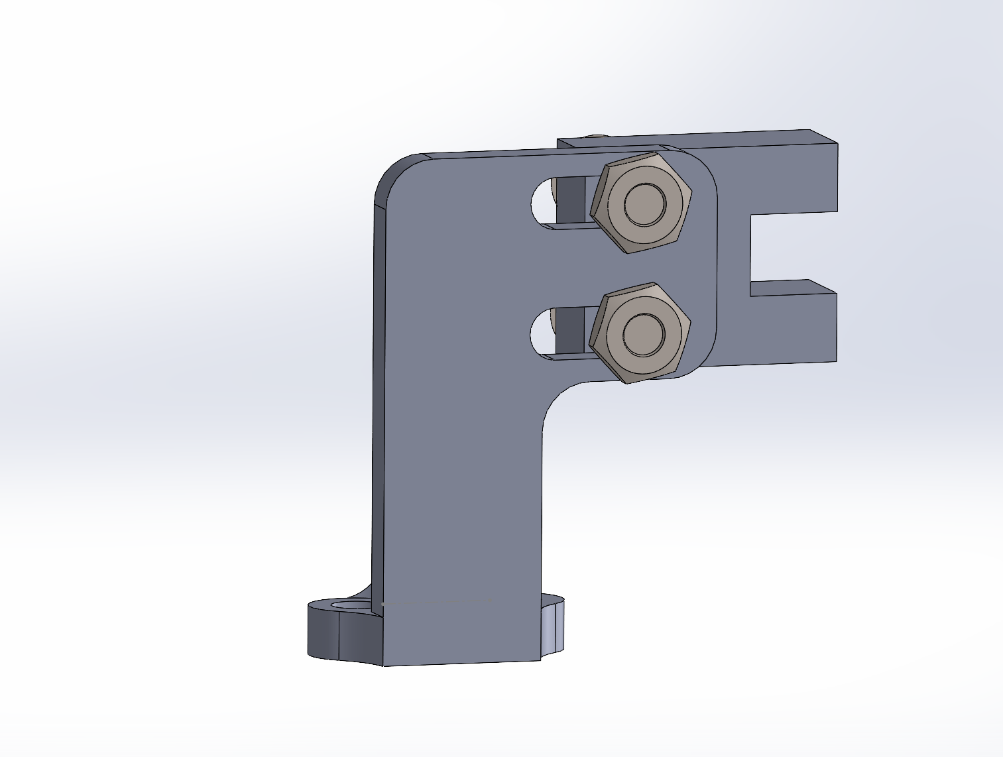
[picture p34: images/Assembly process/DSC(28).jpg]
> 
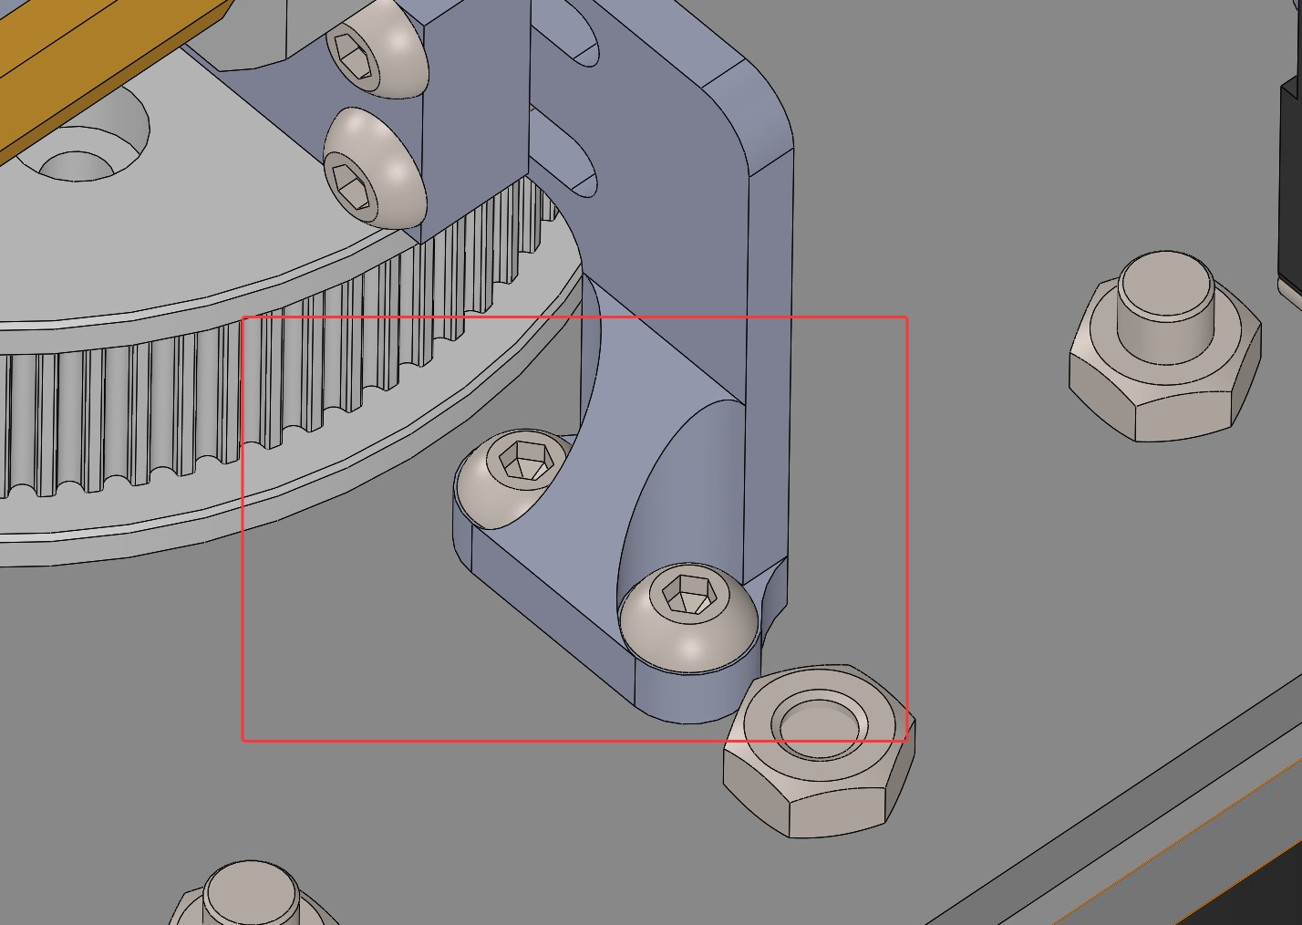
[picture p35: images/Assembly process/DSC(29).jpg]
> 

### 6. 外壳的组装
1.  将组装好RA轴和DEC轴的机械结构通过铝块连接，利用大理石水平面确保所有铝板都能够垂直正交安装并且不会发生干涉
2.  并在螺丝连接处涂抹适量的螺丝胶，确保在设备运行过程中机械连接的稳定性和可靠性

> 📷 *参考图片：*
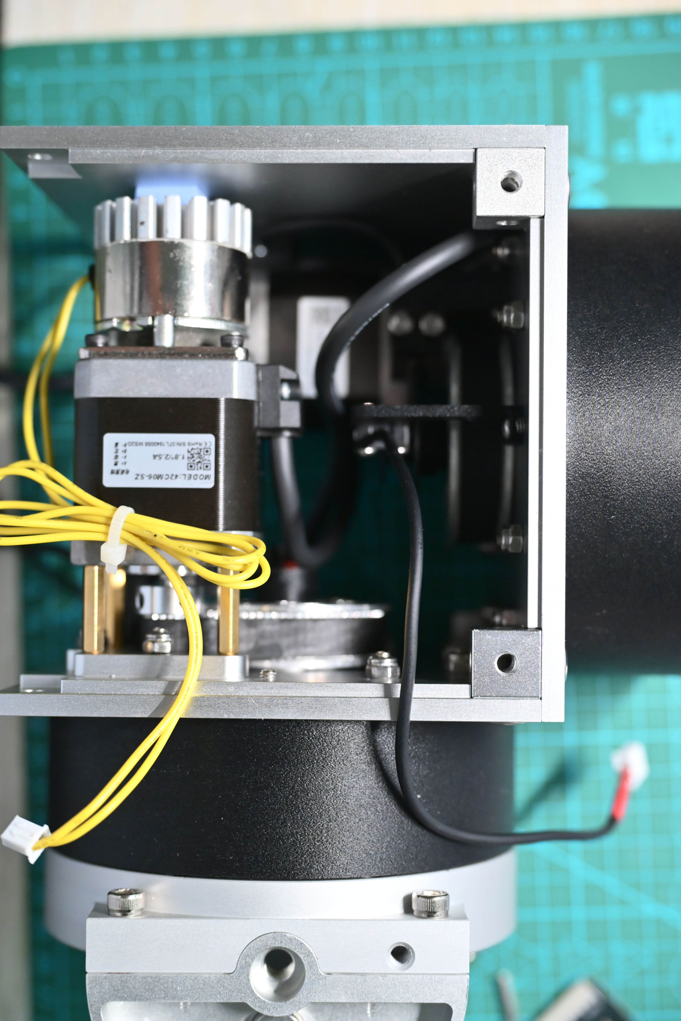
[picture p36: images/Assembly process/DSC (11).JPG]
外壳的组装
> 

---

## ⚡ 阶段三：电控组装与走线

### 1. PCB 底板与驱动安装
1.  将制作好的 PCB 板通过铜柱固定在电控仓内部，安装时请仔细检查背面的 12V/24V 大电流电源平面，确保其与金属外壳之间有足够的绝缘距离。
2.  依次将 TMC5160 驱动模块和 ESP32 主控板插接至对应排母，注意核对引脚方向，切勿插反。

> 📷 *参考图片：*
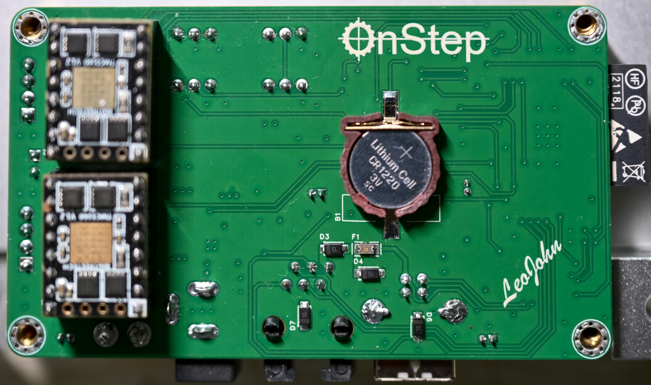
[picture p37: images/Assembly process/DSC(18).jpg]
> 
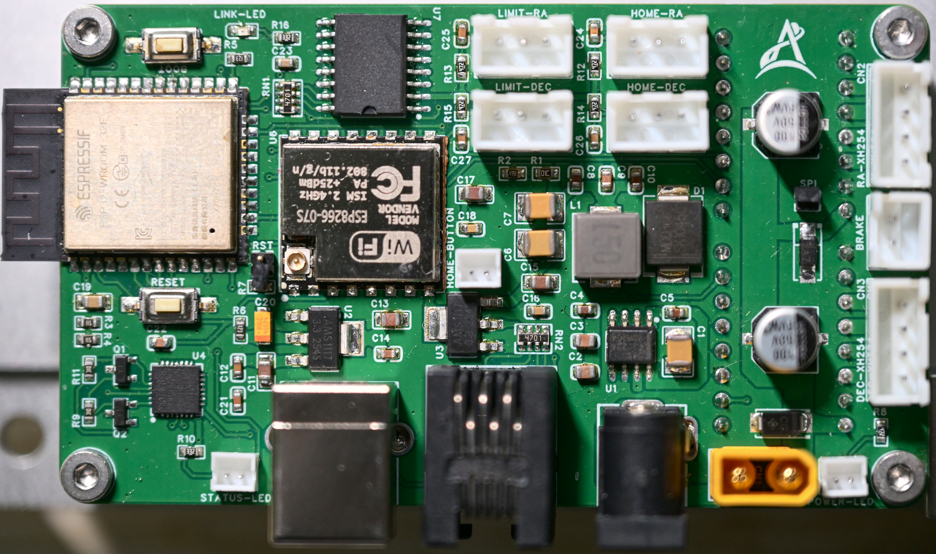
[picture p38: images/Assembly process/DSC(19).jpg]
> 

### 2. 规范接线与理线
为保证设备在野外环境与大电流驱动下的绝对稳定，本项目的接线有着严格的要求：
1.  主电源线路必须使用标准的**电源开关引线**进行连接至 PCB。**严禁使用任何随意的“飞线”**作为电源通路的替代方案。
2.  将 RA 轴和 DEC 轴步进电机的控制线接入 TMC5160 对应的端子。
3.  连接掉电保护系统的控制线，并整理所有线束，确保赤道仪在全方位极限旋转时线缆不会发生缠绕或过度拉扯。

> 📷 *参考图片：*
> 规范的电源引线与内部走线

---

## 💻 阶段四：固件配置与初步调试

赤道仪的硬件逻辑专为标准的 OnStep 环境设计

1.  **固件选择**：系统运行的是**普通的 OnStep 固件**（⚠️请注意：本项目**不适用** OnStepX，切勿刷错固件版本）。
2.  **通讯确认**：确保 ESP32 的引脚映射与您修改好的 OnStep 固件相匹配，同时确认 ESP07S 的网络通讯连接正常。
3.  **上电自检**：接入电源，测试电磁抱闸是否能正常吸合/释放，并通过上位机监测 TMC5160 的运行状态及细分设置。

> 📷 *参考图片：*
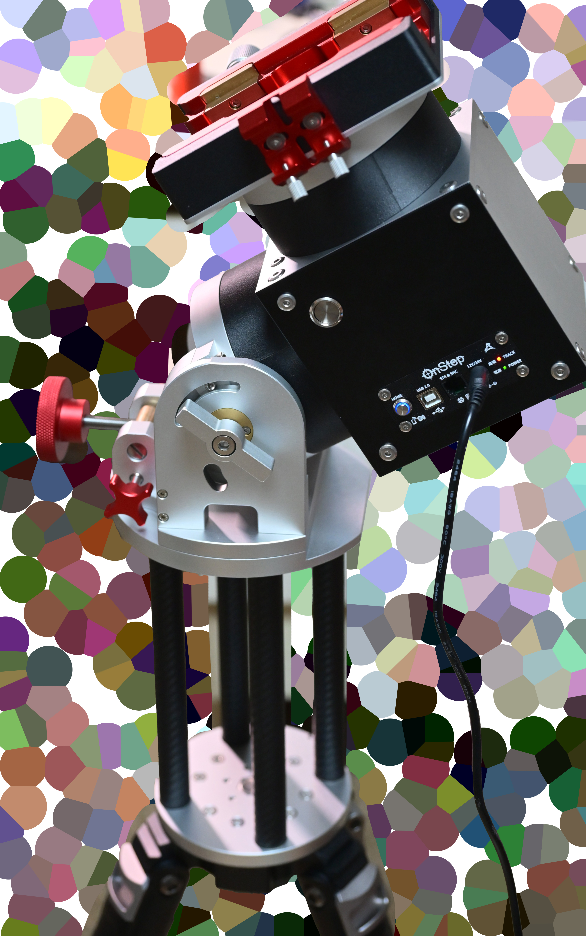
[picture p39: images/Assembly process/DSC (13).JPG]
> 
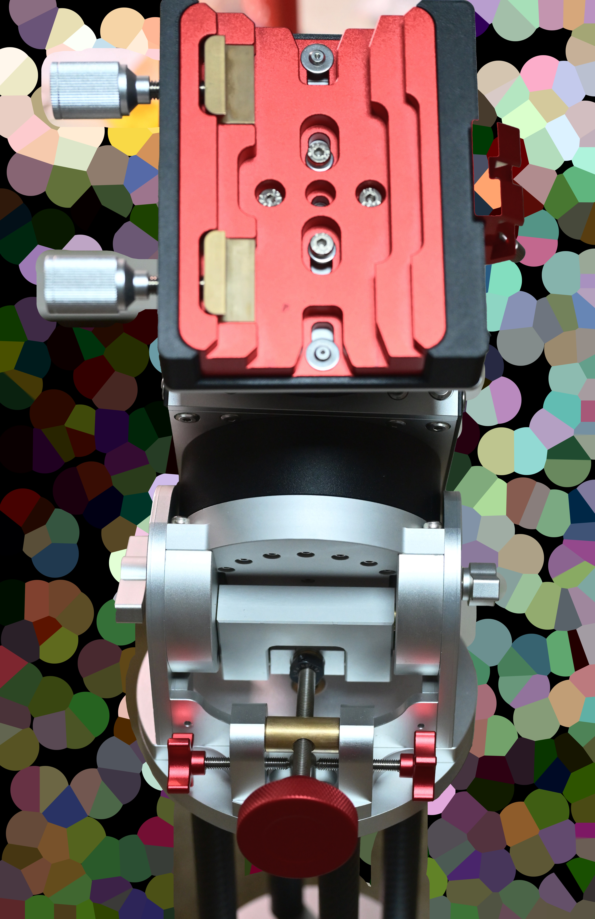
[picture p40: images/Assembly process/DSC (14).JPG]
> 

---

## 🤝 开源协议与贡献
如果您在组装过程中发现了可优化的机械公差或更好的布线方案，欢迎提交 Issue 或 Pull Request，本项目采用 `GPLv3 + CERN-OHL-S` 双开源协议，感谢您对开源天文硬件社区的贡献！

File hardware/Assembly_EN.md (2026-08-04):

<div align="center">
  
  
</div>

# Dual 25-100 Harmonic Equatorial Mount Assembly Instructions

Combining real-life footage from the `images/Assembly process` directory, this guide explains the complete assembly process, from the mechanical structure to the electrical control system, step-by-step.

## 🛠️ Preparation and Materials List (BOM)

Before starting assembly, please ensure you have the following core components and tools ready (refer to the BOM for specific hardware requirements):

* **Transmission Core**: 25-100 type harmonic reducer (1:100 reduction ratio)
* **Idler Gears**: 2GT 10mm wide 80-tooth idler gear and 2GT 10mm wide 19mm high 20-tooth idler gear
* **Motor and Protection**: Stepper motor, power-off brake (electromagnetic damping/holding brake) module
* **Main Control and Drive**: ESP32 + ESP07S combination, TMC5160 stepper motor drive module
* **Circuit Board**: Custom-designed main control PCB (supports 12V/24V power supply)
* **Wires and Accessories:** Power switch leads, various types of Allen screws, lubricant, and screw glue.

*Note: For the idler gear, you need some machining skills to modify the finished idler gear according to the specifications in the drawings. If you cannot modify it, please modify the model to fit standard parts available on the market.*

---

## 🖨️ Phase One: 3D Printing and Machining Preparation

Before formal assembly, it is recommended to complete the following preparations:

1. **3D Printing:** Use PETG-GF/CF material to print all necessary parts, ensuring print quality and dimensional accuracy, especially for key components such as the reducer protective cover, drive shaft, and sensor mounting bracket.

      **Printed Parts List:**

    | Item No. | Part Location | Corresponding Source File |
    | :---: | :--- | :--- |
    | 1 | Main Housing | `Housing.SLDPRT` |
    | 2 | Dovetail Slot Housing | `Dovetail Slot Housing.SLDPRT` |
    | 3 | Declination / Right Ascension Axis | `DEC Axis.SLDPRT` , `RA Axis.SLDPRT` |
    | 4 | Dovetail Slot Housing | `Dovetail Slot Housing.SLDPRT` |
    | 5 | Control Board Cover | `Control Board Cover - Insert.SLDPRT` |
    | 6 | Photoelectric Sensor Mount | `Photoelectric Sensor Mount A.SLDPRT`, `Photoelectric Sensor Mount B.SLDPRT`, `Photoelectric Sensor Mount B - Heightening.SLDPRT` |

> 📷 *Reference Image:*
> 3D Printed Parts
> 3D Printed Parts
> 3D Printed Parts

2. **Fuse Hot-Melt Nuts into Printed Parts:** Before assembly, fuse the prepared hot-melt nuts into all 3D printed parts that require screws. Refer to the markings in the image below for the locations where nuts will be installed. Ensure each nut is securely fixed in the printed part and accurately positioned for easy screw installation during subsequent assembly.

> 📷 *Reference Images:*
> Installing the Hot Melt Nut
> Installing the Hot Melt Nut
> Installing the Hot Melt Nut Installing the thermoplastic nut

3. **Machining**: Modify the idler wheel as necessary to ensure its dimensions and mounting hole positions meet design requirements. Simultaneously, drill and tap holes in the aluminum plate, preparing the necessary screws and copper posts for installation.

---

## ⚙️ Phase Two: Mechanical Structure Assembly

### 1. Harmonic Reducer Installation (RA/DEC Axis)
In this step, we will install the core components of the equatorial mount. Considering the stress requirements of the radial slow-speed rotating load, please ensure that the flange contact surfaces are flat and in close contact during installation.

1. Precisely align the reducer flange face with the screw holes on the aluminum plate, making the center through hole of the aluminum plate as coaxial as possible with the hollow shaft of the reducer. Use hex socket head cap screws and tighten them evenly in a diagonal sequence to ensure uniform stress on the reducer housing and avoid deformation caused by excessive tightness or vibration caused by excessive looseness.
2. Two screw holes require longer screws, and lock nuts are not needed for subsequent motor mount installation.
3. Four screw holes do not require screws for subsequent installation of the 3D-printed reducer protective cover.
4. Tighten the excess parts of the remaining core screw components (excluding those from step 2) into lock nuts to ensure a secure connection between the reducer and the aluminum plate that will not loosen due to vibration.

> 📷 *Reference Images:*
> Installing Harmonic Reducer
> Installing Harmonic Reducer
> Installing Harmonic Reducer

### 2. Transmission Assembly

1. Install the machined 80-gear 2GT idler wheel onto the input shaft of the reducer, ensuring the idler wheel is coaxial with the input shaft. Use Allen screws and tighten them evenly in a diagonal sequence to ensure a secure connection that will not loosen due to vibration.
2. Install the 20-gear 2GT idler wheel onto the output shaft of the stepper motor.
3. Mount the stepper motor onto the motor mount using copper pillars.
4. **Power-off Brake Installation**: Replace the original motor screws at the tail end of the dual-output-axis stepper motor used for the RA axis and install an electromagnetic brake module. This effectively prevents damage to the telescope's "head" due to counterweight imbalance during unexpected power outages.
5. Place a 2GT 10mm wide synchronous belt onto the motor idler wheel beforehand for easier subsequent installation.

> 📷 *Reference Image:*
> RA Axis Motor and Brake Module Installation
> RA Axis Motor and Brake Module Installation
> DEC Axis Motor Installation

### 3. Assembly of RA Axis Latitude Seat Flange
1. 1. Connect the RA shaft flange to connecting shafts A and B using hex socket screws.
2. During step 1, simultaneously assemble the push rod and push block structure, ensuring the push rod can slide smoothly within the push block, and that connecting shafts A and B can achieve relative movement via the push rod.
3. Install the assembled structure from steps 1 and 2 onto the flange of the harmonic reducer using hex socket screws. Simultaneously install the 3D-printed reducer protective cover during the installation process.

> 📷 *Reference Image:*
> Assembly of Latitude Mount
> Assembly of Latitude Mount
> Assembly of Latitude Mount

### 4. Wiring Sequence of Photoelectric Sensor and Motor

1. Confirm that the purchased photoelectric sensor is a slot-type photoelectric switch, four-wire NPN type, and ensure that its output signal is compatible with the input pins of the ESP32 main control board.
2. Configure the wiring of the zero-position sensor (HOME sensor) as follows: brown wire to +5V power supply, blue wire to GND, black wire (i.e., NPN NO).
3. Configure the wiring of the limit sensor (LIMIT sensor) as follows: brown wire to +5V power supply, blue wire to GND, white wire (i.e., NPN NC).
4. Configure the wiring sequence of the motors corresponding to the DEC and RA axes as follows: A-, A+, B+, B-, ensuring the correct phase sequence of the motors.

### 5. Connection of Motor, Synchronous Belt and Reducer, and Installation of Sensor and Flange

1. Install the motor onto the longer screws pre-drilled on the aluminum plate in step 1 through the pre-drilled holes on the motor mount. Tighten the synchronous belt and tighten the anti-loosening nuts on the screws to ensure that the synchronous belt does not slip or become excessively loose during transmission.
2. Adjust the height of the idler pulley on the motor output shaft appropriately so that it is on the same horizontal plane as the idler pulley on the reducer input shaft. This ensures even tension distribution of the synchronous belt and avoids excessive wear or reduced transmission efficiency due to non-parallelism.
3. After completing the above steps, manually rotate the large idler pulley to check if the synchronous belt runs smoothly and ensure there are no abnormal friction sounds or vibrations. This will help confirm the correct installation and adjustment of the transmission system.
4. After installation, it is recommended to spray an appropriate amount of silicone lubricant on the synchronous belt to reduce friction and abnormal noise and extend the service life of the synchronous belt.
5. Install the photoelectric sensor limit switches and origin switches on the RA/DEC shafts to ensure that their positions can accurately detect the extreme positions and origin positions of the shaft for safety protection and precise positioning.
6. Install the 3D-printed reducer protective cover on the outside of the reducer, using the pre-drilled screw holes and hex socket screws for fixing. This ensures that the protective cover can effectively prevent dust and debris from entering the reducer without interfering with its normal operation.
7. Install the flange of the RA/DEC shaft, ensuring it is coaxial with the shaft, and tighten it evenly with Allen screws to ensure the flange does not shift or loosen during operation.

> 📷 *Reference Image:*
> RA shaft motor and brake module, sensor, flange installation Installation of RA axis motor, brake module, sensor, and flange
> DEC axis motor, timing belt
> DEC axis flange installation
> Sensor Installation
> Sensor Installation
> Sensor Installation

### 6. Housing Assembly
1. Connect the assembled RA and DEC axes mechanical structures using aluminum blocks. Utilize a marble-like horizontal surface to ensure all aluminum plates are installed perpendicularly and orthogonally without interference.
2. Apply an appropriate amount of screw glue to the screw connections to ensure the stability and reliability of the mechanical connections during equipment operation.

> 📷 *Reference Image:*
> Shell Assembly

---

## ⚡ Phase Three: Electrical Control Assembly and Wiring

### 1. PCB Base Plate and Driver Installation

1. Fix the assembled PCB board inside the electrical control compartment using copper pillars. During installation, carefully check the 12V/24V high-current power supply plane on the back to ensure sufficient insulation distance between it and the metal casing. 2. Connect the TMC5160 driver module and the ESP32 main control board to the corresponding female connectors in sequence, carefully checking the pin orientation to ensure they are correctly connected.

> 📷 *Reference Images:*
> PCB and Driver Installation
> PCB and Driver Installation

### 2. Standard Wiring and Cable Management To ensure the absolute stability of the equipment in outdoor environments and under high current driving conditions, the wiring in this project has strict requirements:

1. The main power supply line must use standard **power switch leads** to connect to the PCB. **The use of any arbitrary "flying wires"** as a substitute for the power path is strictly prohibited.
2. Connect the control cables for the RA and DEC axis stepper motors to the corresponding terminals on the TMC5160.
3. Connect the control cables for the power-off protection system and tidy up all wiring harnesses to ensure that the cables do not become tangled or excessively stretched during the equatorial mount's extreme rotation.

> 📷 *Reference Image:*
> Standard Power Leads and Internal Routing

---

## 💻 Phase Four: Firmware Configuration and Initial Debugging

The equatorial mount's hardware logic is designed specifically for the standard OnStep environment.

1. **Firmware Selection**: The system runs **standard OnStep firmware** (⚠️Please note: This project **does not apply** OnStepX; do not flash the wrong firmware version).
2. **Communication Confirmation**: Ensure the ESP32 pin mapping matches your modified OnStep firmware, and confirm the ESP07S's network communication connection is normal. 3. **Power-on Self-Test:** Connect to power and test whether the electromagnetic brake can engage/release normally. Monitor the operating status and microstepping settings of the TMC5160 via the host computer.

> 📷 *Reference Images:*
> Electronic Control System Lighting and Online Testing
> Electronic Control System Lighting and Online Testing

---

## 🤝 Open Source License and Contributions

If you find any optimizable mechanical tolerances or better wiring solutions during the assembly process, please submit an Issue or Pull Request. This project uses `GPLv3 + CERN-OHL-S` Dual open-source license, thank you for your contributions to the open-source astronomical hardware community!

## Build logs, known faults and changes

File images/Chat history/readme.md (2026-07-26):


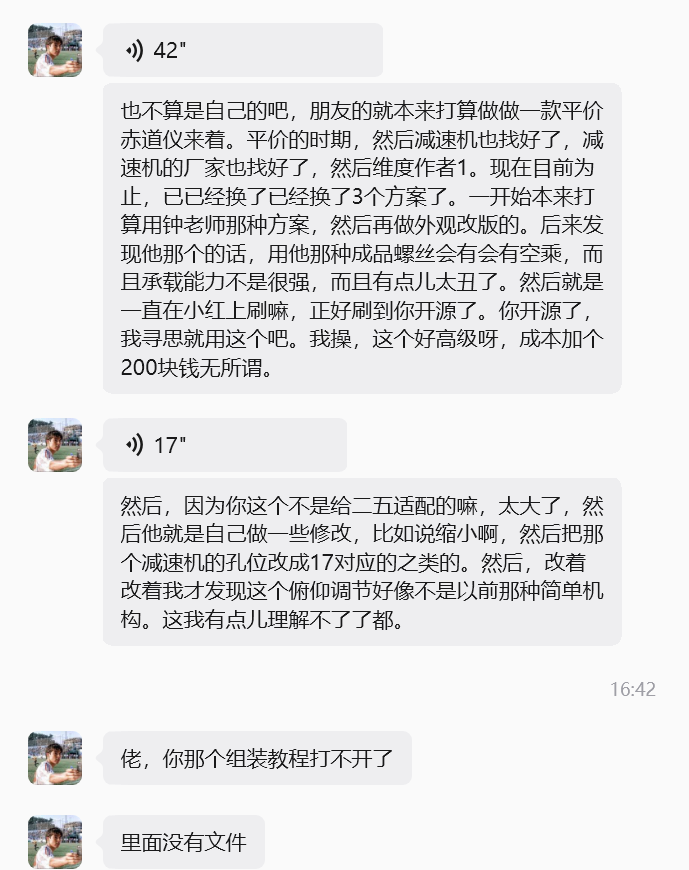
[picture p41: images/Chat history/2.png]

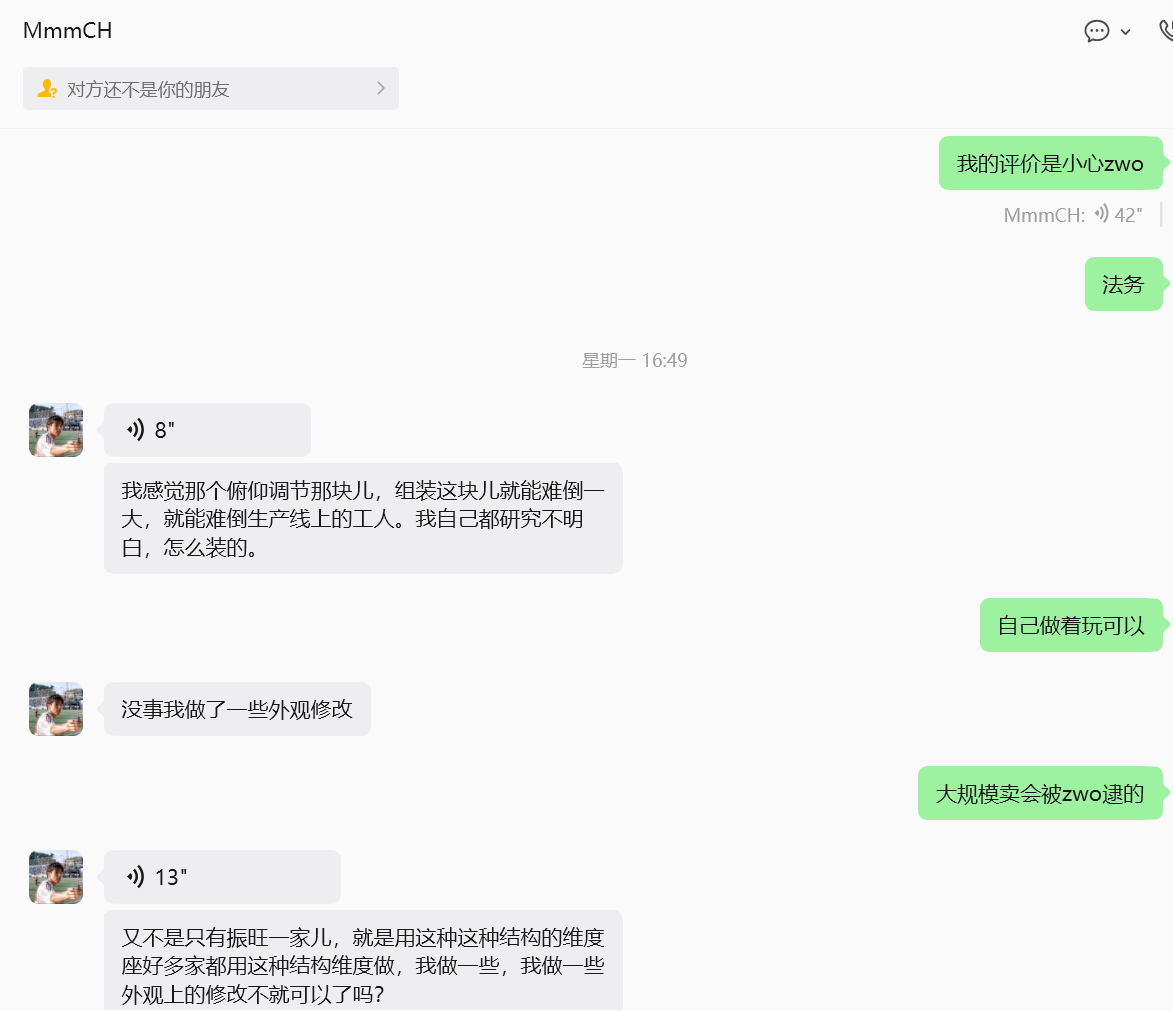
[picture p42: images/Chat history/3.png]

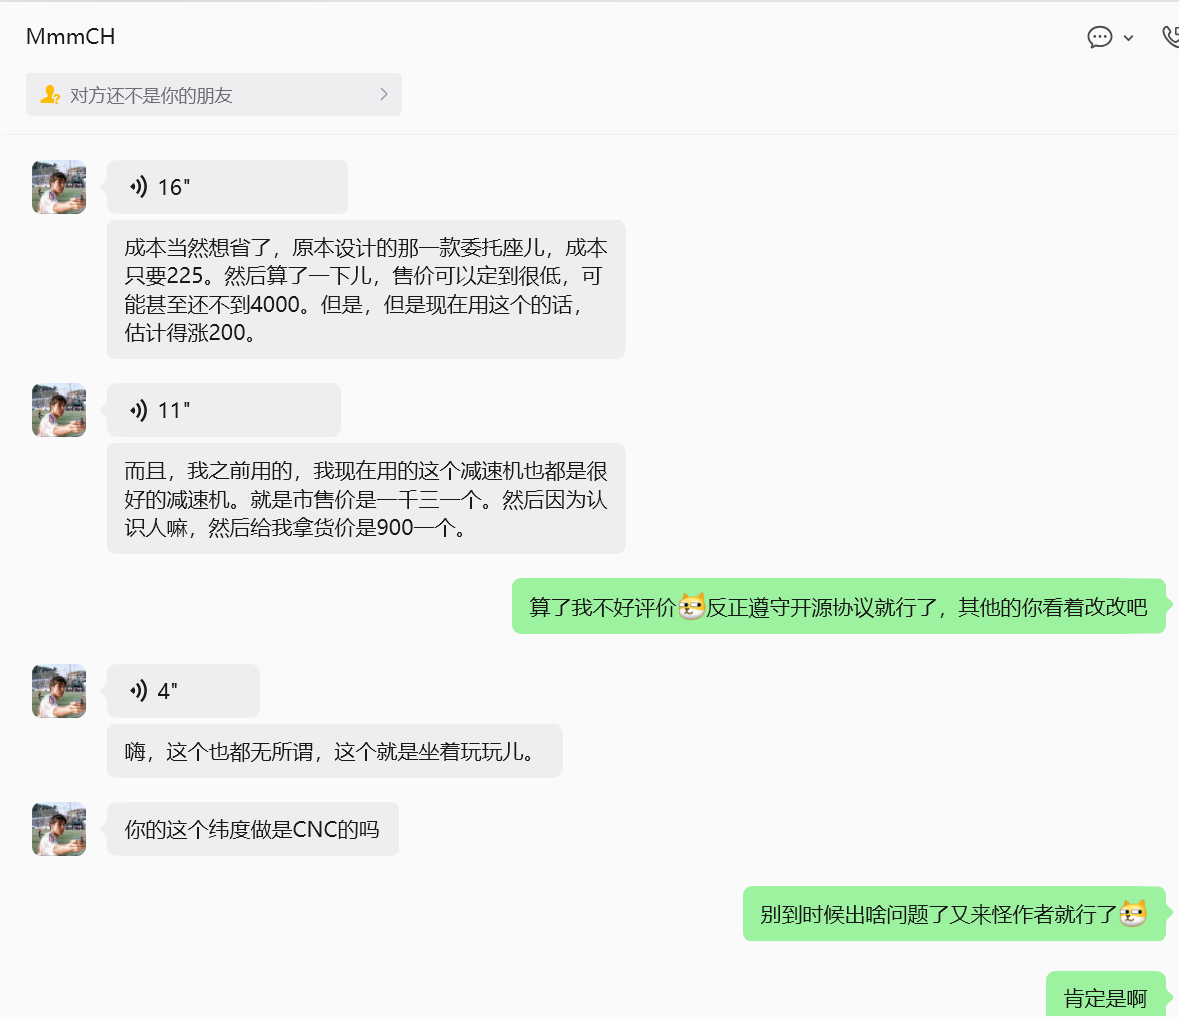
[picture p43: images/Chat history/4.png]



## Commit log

2026-05-15 update readme.md with code modification guide for motor enable on startup to prevent slippage
2026-07-27 fix: update PCB images in README.md
2026-08-02 updated Gerber PCB files to include a version without Vbus power and renamed the original Gerber PCB file to include "Gerber" in the filename for clarity.
2026-08-04 update Assembly.md and Assembly_EN.md
2026-08-17 去掉多余的标点符号
2026-08-18 修改标点
2026-08-18 readme.md补充说明
2026-08-18 补充许可证
